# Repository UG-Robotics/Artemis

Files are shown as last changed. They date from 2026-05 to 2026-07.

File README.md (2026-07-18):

# Artemis — WRO 2026 Future Engineers

**Team Artemis · UGhana Robotics · University of Ghana**

Artemis is an autonomous self-driving vehicle built for the [WRO Future Engineers](https://wro-association.org/) 2026 season. Our core engineering idea is **one brain, two bodies**: the control logic is developed and validated in a purpose-built 2D simulator, then the *same code* drives the physical robot through a thin hardware-abstraction layer. Every algorithm on the vehicle was tuned against hundreds of simulated runs before it ever touched the mat.

## Contents

- [Repository structure](#repository-structure)
- [The challenge](#the-challenge)
- [The vehicle](#the-vehicle)
- [1. Mobility and mechanical design](#1-mobility-and-mechanical-design)
- [2. Power and sensor architecture](#2-power-and-sensor-architecture)
- [3. Software architecture](#3-software-architecture)
- [4. Engineering decisions and lessons](#4-engineering-decisions-and-lessons)
- [5. Reproducing the robot](#5-reproducing-the-robot)
- [Testing workflow](#testing-workflow)
- [Status](#status)

## Repository structure

```
artemis/
├── src/
│   ├── core/                    # Shared control brain — runs in BOTH sim and robot
│   ├── sim/
│   │   ├── open-challenge-sim/  # 2D simulator, viewer, and test suites
│   │   └── obstacle-challenge-sim/
│   └── robot/                   # Raspberry Pi runtime: drivers, HAL, entry points
│       ├── drivers/             # motor, servo, ToF, IMU, color, camera
│       ├── bench/               # per-device bring-up & diagnostic scripts
│       └── web/                 # teleop + telemetry dashboard (systemd service)
├── docs/                        # Engineering docs: power & sensors writeup, BOM, wiring PDF
├── schemes/                     # Wiring diagram (PNG/SVG) + docs/schematics/ PDF
├── models/                      # CAD: cad-source/ (STEP), print/ (STL), v1/ (retired design)
├── v-photos/                    # Vehicle photos (6 views)
├── t-photos/                    # Team photos
└── video/                       # Run videos + YouTube link (video.md)
```

## The challenge

A vehicle must complete **three autonomous laps** on a track whose geometry is randomized every round: the **Open Challenge** varies the track width between 600 and 1000 mm, and the **Obstacle Challenge** adds red/green traffic pillars (red → pass on the right, green → pass on the left), a possible mid-run direction reversal, and finishes with **parallel parking** into a slot only 1.5× the vehicle length. Official rules: [WRO Future Engineers 2026](https://wro-association.org/competition/2026-season/).

## The vehicle

Six views of the vehicle are in [`v-photos/`](v-photos). Key figures (current, generation-2 chassis — measured from the CAD assembly):

| Property | Value |
|---|---|
| Footprint over wheels | ≈ 208 mm × 148 mm (rules allow 300 × 200) |
| Height | ≈ 100 mm (equal to the track wall height; limit 300) |
| Wheelbase / track | ≈ 152 mm / ≈ 120 mm |
| Wheels | ⌀ ≈ 55 mm rubber, 4-spoke |
| Drive | Single JGA25-370 12 V DC gearmotor, rear axle |
| Steering | Front-wheel, SG90 servo, ±35° measured linkage throw |
| Compute | Raspberry Pi 3B+ |
| Power | 7.4 V 2S LiPo, 5000 mAh (built-in protection board) + XL4015 buck for the 5 V rail |

This is our **second chassis generation** (see §1 and [`models/README.md`](models/README.md) for the full story). The simulator's kinematic constants in [`src/core/config.py`](src/core/config.py) now model this chassis (208 mm, 152 mm wheelbase, ⌀55 mm wheels, 300 RPM rated drive), and the open-challenge controller was re-tuned and re-validated in simulation against the new geometry. Constants that can only be confirmed on the physical robot — such as the measured wheel RPM under load — still carry an explicit `VERIFY` marker in [`src/robot/hardware_config.py`](src/robot/hardware_config.py) until they have been bench-measured.

## 1. Mobility and mechanical design

- **Servo-driven front steering.** The front wheels steer through a king-pin linkage driven by the SG90's horn; we measured the real assembled throw at ±35° and use that as the software steering limit. Our first-generation chassis used explicit Ackermann geometry (inner wheel turns tighter — see [`models/README.md`](models/README.md)), and that design reasoning carried into the current steering setup.
- **Single-motor rear drive**, as required by the rules — one 12 V-rated DC gearmotor on the rear axle. The motor's encoder is **not used** in the current build: the controllers are deliberately encoder-free, taking distance context from the ToF array and heading from the IMU, so the wheel-RPM measurement (`VERIFY` in `hardware_config.py`) only calibrates the speed model, not a control loop.
- **Two chassis generations.** Our first fully 3D-printed design ([`models/v1/`](models/v1)) packed everything into a 140 mm shell for protection — and taught us a hard lesson: it was so cramped that every wiring fault meant a full teardown, which cost us days during electrical bring-up (§4). Generation 2 is a longer 208 mm chassis plate carrying a custom-designed **tub + lid body** ([`models/cad-source/`](models/cad-source) STEP sources, [`models/print/`](models/print) print-ready STLs): the screw-on lid comes off to expose the entire loom and every board for probing, the battery pack rides in a 24 mm service bay *under* the tub on metal standoffs, and the walls carry apertures for all four ToF sensors, the camera nose, the power switch, and the start button. The full iteration history (10 body revisions, with what each one fixed) is in [`models/README.md`](models/README.md).

## 2. Power and sensor architecture

Wiring diagram: [`schemes/circuit_image.png`](schemes/circuit_image.png) (editable SVG alongside; full schematic PDF in [`docs/schematics/`](docs/schematics)). **Full writeup — power budget, bus architecture, placement rationale, calibration procedures, and failure modes: [`docs/power-and-sensors.md`](docs/power-and-sensors.md).** Highlights:

**Power.** A 7.4 V 2S LiPo pack (5000 mAh, built-in dual-protection board, mounted in the under-tub bay) feeds the drive motor directly through the H-bridge; an XL4015 buck converter steps down to 5 V for the Pi, servo, and sensors, isolating logic from motor sag. Cost breakdown of the full build: [`docs/bom.md`](docs/bom.md).

**Sensors and why we chose them:**

| Sensor | Role | Placement rationale |
|---|---|---|
| 4× VL53L1X ToF | Wall ranging (front/left/right/rear) | Long-distance mode (≤3.6 m) covers the full 1000 mm track width with margin; left/right pair gives centring error, front detects the corner wall, rear disambiguates the start section |
| LSM6DSOX IMU | Heading (gyro-hold mode) | Bench-measured ≈0.07°/min raw drift; startup bias calibration + zero-velocity updates |
| TCS34727 color | Corner lines (orange/blue) | Downward-facing; the mat lines are the rules' ground-truth corner trigger |
| OV5647 camera | Pillar detection + heading fusion | Forward, processed on the Pi at 640×480 |

**Bus engineering that cost us real debugging time** (all documented in the code):
- All four VL53L1X ship at the same I2C address, so each is enabled sequentially via its XSHUT pin and reassigned to 0x30–0x33 at boot ([`src/robot/hardware_config.py`](src/robot/hardware_config.py)).
- The color sensor's fixed 0x29 address **clashes** with the ToF default, so it lives on its own software I2C bus (i2c-gpio overlay on GPIO20/21).
- The Pi's I2C clock is lowered to 50 kHz — at the default 100 kHz the VL53L1X's long init transactions fail intermittently on our loom.
- Every calibration constant that hasn't been verified on the physical build is explicitly marked `VERIFY` in `hardware_config.py`, so nothing silently runs on a guess.

## 3. Software architecture

Three layers ([`src/README.md`](src/README.md)):

- **`core/`** — the brain. Pure Python, no hardware imports. The primary [`Controller`](src/core/controller.py) is a state machine (below); [`WallFollowController`](src/core/wall_follow_controller.py) is a ToF-only alternative brain (§4). Both expose the identical `update(sensors, robot, track, dt)` contract.
- **`sim/`** — a 2D simulator with a pygame viewer, randomized track configs, and scored test suites.
- **`robot/`** — the Pi runtime: `RealHardware` implements the same interface the simulated robot does, so a controller cannot tell which body it is driving.

Primary controller state machine:

```mermaid
stateDiagram-v2
    [*] --> STARTING
    STARTING --> WALL_FOLLOWING
    WALL_FOLLOWING --> CORNER_TURN: corner line detected
    CORNER_TURN --> WALL_FOLLOWING: heading changed 90°
    WALL_FOLLOWING --> PILLAR_AVOIDANCE: pillar in path
    PILLAR_AVOIDANCE --> WALL_FOLLOWING: pillar cleared
    WALL_FOLLOWING --> THREE_POINT_TURN: reversal condition
    THREE_POINT_TURN --> WALL_FOLLOWING
    WALL_FOLLOWING --> PARKING: 3 laps (obstacle)
    WALL_FOLLOWING --> STOP_SECTION: 3 laps (open)
    PARKING --> [*]
    STOP_SECTION --> [*]
```

Straights are a **PD controller** on the left/right ToF difference (centring), with a heading term toward the nearest cardinal direction; corners drive a bicycle-model arc whose radius is computed live from the inner-wall distance; pillar avoidance is a bounded heading-offset "weave" that snapshots the lane heading and hinges around the pillar on the rule-mandated side. Laps are counted from the mat's colored lines with distance-based dedup (8 sections = 1 lap).

The real-robot entry point [`src/robot/open_challenge.py`](src/robot/open_challenge.py) can run **three brains** selected by flag — `--mode tof` (wall-follower, the proven baseline), `--mode fusion` (ToF + camera heading blend, 0.7/0.3), `--mode imu` (gyro heading-hold) — which lets us swap strategy at the track without code changes.

Every run is recorded by a **flight recorder** ([`src/robot/run_logger.py`](src/robot/run_logger.py)): 30 Hz sensor CSV, 10 Hz camera detections, keyframe JPEGs, and metadata including the deployed git revision. [`src/robot/bench/log_timeline.py`](src/robot/bench/log_timeline.py) replays a run as a timeline with an ASCII path plot, which is how we debug field behaviour after the fact.

## 4. Engineering decisions and lessons

The decisions that shaped the robot, with the evidence behind them:

- **Sim-first development.** Building the simulator before the robot let us tune the PD gains and corner geometry across 48 randomized edge-case configurations — all 48 complete three laps in the open-challenge suite. When hardware later failed (below), the sim is also what let us validate a replacement strategy in one evening.
- **The counterfeit IMU.** Our original "MPU6050" answered WHO_AM_I with 0x98 — a non-functional counterfeit. We replaced it with a genuine LSM6DSOX, bench-measured its drift (≈0.07°/min), and the IMU driver now **verifies the chip ID at startup** so a swapped or fake part fails loudly instead of navigating badly.
- **A second brain instead of a blocked robot.** While the IMU was dead, the gyro heading-hold controller couldn't drive. Rather than wait on parts, we wrote `WallFollowController` — open-challenge navigation from the four ToF sensors alone (no IMU, no color, no pose), validated in the sim before deployment. It remains our most robust fallback, and the `--mode` flag makes the choice a run-time decision.
- **Motor driver forensics.** The TB6612FNG's channel B died at chip level. GPIO-probe bench scripts ([`src/robot/bench/motor_test/`](src/robot/bench/motor_test)) isolated the fault to the chip rather than wiring or code; we moved the motor to channel A and left the diagnostic scripts in the repo.
- **Chassis v1 → v2** (§1): compactness lost to serviceability once real debugging started.
- **Exclusive camera ownership.** The teleop dashboard and the autonomous runtime both want the camera; Picamera2 allows one owner. The run entry point guards against the web service holding it, and the boot-run systemd unit declares `Conflicts=artemis-web` so the two can never fight during a competition start.

## 5. Reproducing the robot

**Build:** print everything in [`models/print/`](models/print) (PLA, 0.2 mm layers; STEP sources in `cad-source/` for modification), assemble per the mechanical notes in [`models/README.md`](models/README.md), and wire following [`schemes/`](schemes).

**Pi setup (Raspberry Pi OS):**
1. In `/boot/firmware/config.txt`: enable I2C with `dtparam=i2c_arm_baudrate=50000`, and add the software I2C bus for the color sensor: `dtoverlay=i2c-gpio,bus=3,i2c_gpio_sda=20,i2c_gpio_scl=21`.
2. Install dependencies: `pip install -r requirements-robot.txt` plus the apt packages listed in that file (`picamera2`/`opencv` install via apt on Raspberry Pi OS).
3. Copy the repo's `src/` to `/home/pi/artemis/src` (we deploy with `rsync`; the deploy stamps the git revision into `DEPLOYED_REV` so run logs record which code ran).
4. Verify each device independently with the scripts in [`src/robot/bench/`](src/robot/bench) (I2C scan, per-sensor live reads, servo jog, motor probe, button test), then fill in any `VERIFY` constants in `hardware_config.py`.

**Run:**
```bash
# On the Pi, from /home/pi/artemis/src:
python3 -m robot.open_challenge                    # ToF-only, waits for start button
python3 -m robot.open_challenge --mode imu --direction cw
python3 -m robot.web.app                           # teleop/telemetry dashboard :8000
```
For competition starts with no laptop attached, the `artemis-run` systemd unit boots the Pi straight to button-armed in ≈23 s, runs exactly one attempt, and cuts motors on stop ([`src/robot/artemis-run.service`](src/robot/artemis-run.service)).

**Simulator (any machine):**
```bash
pip install -r requirements.txt
cd src/sim/open-challenge-sim
python sim_viewer.py        # real-time visualizer (SPACE pause, ←/→ configs, T sensor rays)
python test_pd_tuning.py    # scored PD/navigation suite
```

## Testing workflow

Full documentation with the per-suite pass bars: [`tests.md`](tests.md). In short:

1. **Simulate** — every control change must pass the scored sim suites (`test_pd_tuning.py`, `test_open_score.py`, plus headless and sensor-noise tests) across the randomized configs before it is deployed.
2. **Bench** — new or repositioned hardware goes through its `robot/bench/` script in isolation before joining the control loop.
3. **Field + flight recorder** — real runs are logged automatically (sensors, camera, frames, git revision) and replayed with `log_timeline.py`; changes prompted by a field failure are reproduced in the sim first, fixed in `core/`, and re-validated so sim and robot never diverge.

## Status

- **Open challenge:** ToF wall-follower validated in sim (48/48 edge-case configs, 30/30 score) and driving on the physical robot; on-mat tuning in progress.
- **Obstacle challenge:** pillar-avoidance and parking logic complete in the primary controller and sim; camera color calibration and on-robot integration in progress.
- Run videos: [`video/video.md`](video/video.md).

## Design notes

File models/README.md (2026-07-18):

# Models — mechanical design & CAD

CAD for the Artemis vehicle, in two generations:

```
models/
├── cad-source/   # Current (gen-2) design — editable STEP sources
│   ├── New assembly test on new.step   # Full rolling-chassis assembly (frame,
│   │                                   #  wheels, steering, JGA25-370, SG90, tub)
│   ├── New assembly test on new.f3d    # Fusion 360 source of the assembly
│   ├── full_assembly_with_lid.step     # Assembly + lid placed (render-ready)
│   ├── Improved frame.step   # Chassis base plate (71 × 171 mm)
│   ├── body.step             # Tub + lid combined, in assembled position
│   ├── body_tub.step / body_lid.step / legs.step
│   └── *_print.stl           # Bed-oriented exports (duplicated in print/)
├── print/        # Current design — print-ready STLs
└── v1/           # Retired first-generation design (kept for the record)
```

## Current design (generation 2, July 2026)

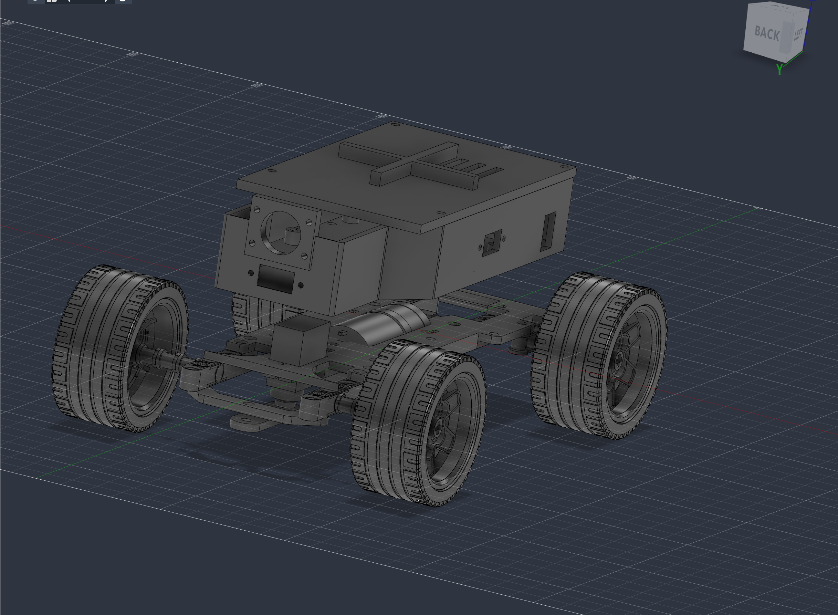
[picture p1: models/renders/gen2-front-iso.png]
Gen-2 assembly, front isometric render

<div align="center">
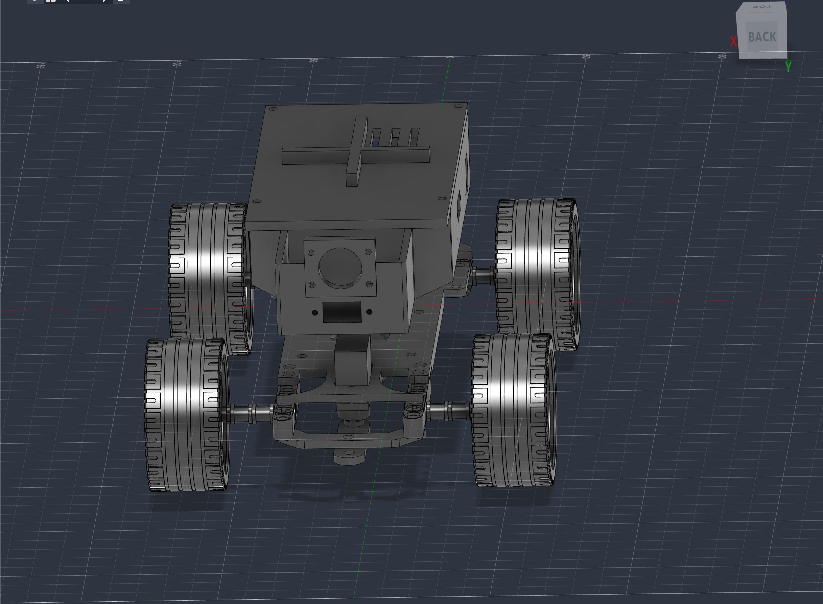
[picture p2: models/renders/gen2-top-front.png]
Gen-2 top-front render

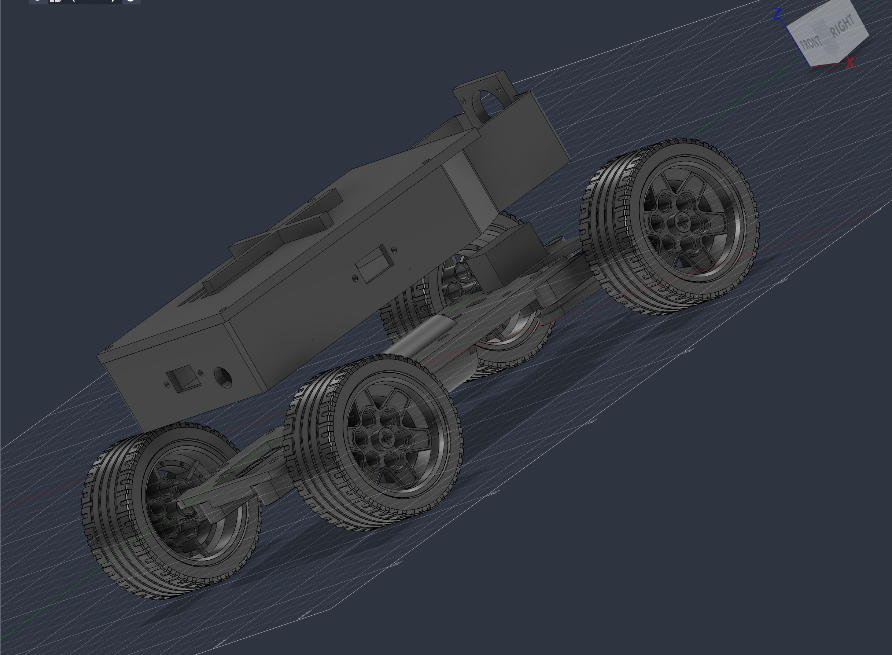
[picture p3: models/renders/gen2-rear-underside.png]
Gen-2 rear underside render

</div>

*Renders of [`cad-source/full_assembly_with_lid.step`](cad-source/full_assembly_with_lid.step) in Fusion 360 — lid on, camera nose and ToF/button apertures visible.*

The vehicle is built on a **208 mm chassis** (measured over the wheels: ≈208 L × 148 W mm, ≈100 mm tall — exactly the track wall height, well inside the 300 × 200 × 300 limit). The rolling chassis — frame plate, steering, motor, and ⌀≈55 mm wheels, wheelbase ≈152 mm — was built by our mechanical engineer; the **body is our own design**.

### Body architecture: tub + lid

- **Tub** (`body_tub`): an open box that screws onto the frame's top-deck M3 holes and hosts the Raspberry Pi 3B+ on a standard 58 × 49 mm standoff pattern. The walls carry purpose-cut apertures: horizontal 14 × 8 mm windows for all four VL53L1X ToF boards (front/left/right/rear, boards self-tapped to the wall), a camera nose tower for the OV5647, the power rocker on the left wall, and the 12 mm start button on the rear wall. Seven floor pass-throughs route the loom.
- **Lid** (`body_lid`): a 3.5 mm screw-on cover (6 screws). The IMU bolts up through the lid into its stiffening ribs — an earlier revision used a printed boss, which we deleted when rib-mounting proved stiffer against motor vibration. The nose is deliberately left open so the lid never occludes the camera.
- **Under-tub service bay**: the tub floor sits 24 mm above the frame on **4 × M3×24 metal hex standoffs**, creating a bay beneath it for the heaviest item — the battery — kept low and central for stability. The bay was originally sized around a 3 × 18650 holder (75 × 60 × 18 mm); the pack has since been replaced by a 2S LiPo brick that lives in the same bay. `legs.step` is an optional printed alternative to the standoffs.

**Serviceability is the design's organizing principle** (see *Why we redesigned* below): lid off = every board and the full loom exposed; battery slides out of the open-sided bay without touching the electronics.

### Print notes

Printed on a Bambu Lab P1S, PLA, 0.2 mm layers. `body_tub_print.stl` and `body_lid_print.stl` are already bed-oriented: the tub prints floor-down (light supports only in window/aperture overhangs), the lid prints flat with **no supports**. All holes are self-tap pilot or clearance sizes — no printed threads.

### Iteration history (what ten body revisions taught us)

The body went through ~10 design revisions before printing. The instructive failures:

1. **The battery drove the architecture.** The 60 mm-wide holder physically could not fit between the tub's original corner legs on a 71 mm frame plate. We evaluated three placements (under-chassis, in-tub, on-lid) against center-of-mass and access, and settled on the under-tub bay — the decision that produced the standoff design.
2. **Integral legs doubled the print.** Printing the tub with its four 24 mm legs forced ~35 g of tree support under the raised floor and pushed the print past 5 hours. Deleting the legs (tub flat on the bed) and bridging with metal standoffs cut support material to grams — and the metal is stronger anyway.
3. **Wall cut-outs must overshoot.** Twice, a window boolean that extended exactly *to* the inner wall face left a 0.5 mm skin over the opening. Rule adopted: every cut box extends past the face it opens.
4. **Fit is checked against measured boards, not datasheet folklore.** The first external body design had the Pi hole pattern, switch cut-out, and ToF mounts wrong; we re-measured every component before modeling. The ToF windows also flipped from vertical to horizontal once we checked the actual board's long axis.
5. **Controls placement followed usage.** The start button began on the left wall 1.5 mm from the Pi — reachable, but only just. It ended up on the rear wall next to the rear ToF, 20+ mm clear of everything, where a start press can't disturb the wiring.

## Generation 1 (retired — `v1/`)

The first vehicle was a fully 3D-printed 140 × 88 × 56 mm design (76 mm wheelbase, ⌀30.4 mm LEGO wheels) built around two objectives: **compactness and component protection**. Everything lived inside the shell to protect the electronics, with a slip-fit body-to-chassis joint and ventilation cut-outs.

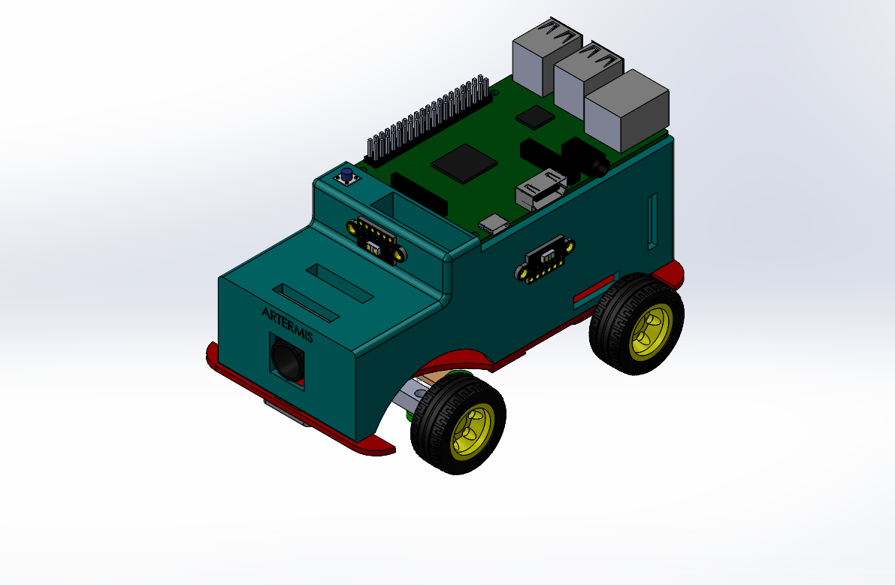
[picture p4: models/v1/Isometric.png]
v1 isometric view


Its mechanical highlights, which still inform the current vehicle:

- **Ackermann steering geometry** — the inner wheel turns at a greater angle than the outer during cornering, reducing slip; actuated by the servo horn directly on the steering linkage. We validated the geometry in simulation before printing:

  v1 steering simulation

- **Single-motor rear drive through a custom gearbox** (bevel gears, 1:1 ratio) — the ratio preserved the motor's rated speed, prioritizing lap time over torque, because the vehicle was light enough that torque was never the constraint. A wheel encoder was wired for odometry experiments, but never adopted — the control stack ended up deliberately encoder-free (ToF distances + gyro heading).
- **Iterative chassis lightening** — material removed for steering clearance, thinner base with reinforcement extrusions at load points:

  <div align="center">
  v1 first chassis iteration ➡️
  v1 final chassis iteration
  </div>

**Why we retired it:** the very compactness we optimized for became the bottleneck the moment electrical bring-up started. Diagnosing a single suspect jumper meant disassembling the stacked body, and with the debugging phase producing faults weekly (dead motor-driver channel, counterfeit IMU, sensor repositioning — see the [root README §4](../README.md#4-engineering-decisions-and-lessons)), teardown cost dominated. The 208 mm generation-2 platform trades footprint for a longer wheelbase (steadier tracking), larger wheels, and above all **access**: nothing on the current robot requires removing more than the lid to reach.

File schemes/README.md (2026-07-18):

# Schemes — wiring & electromechanical diagrams

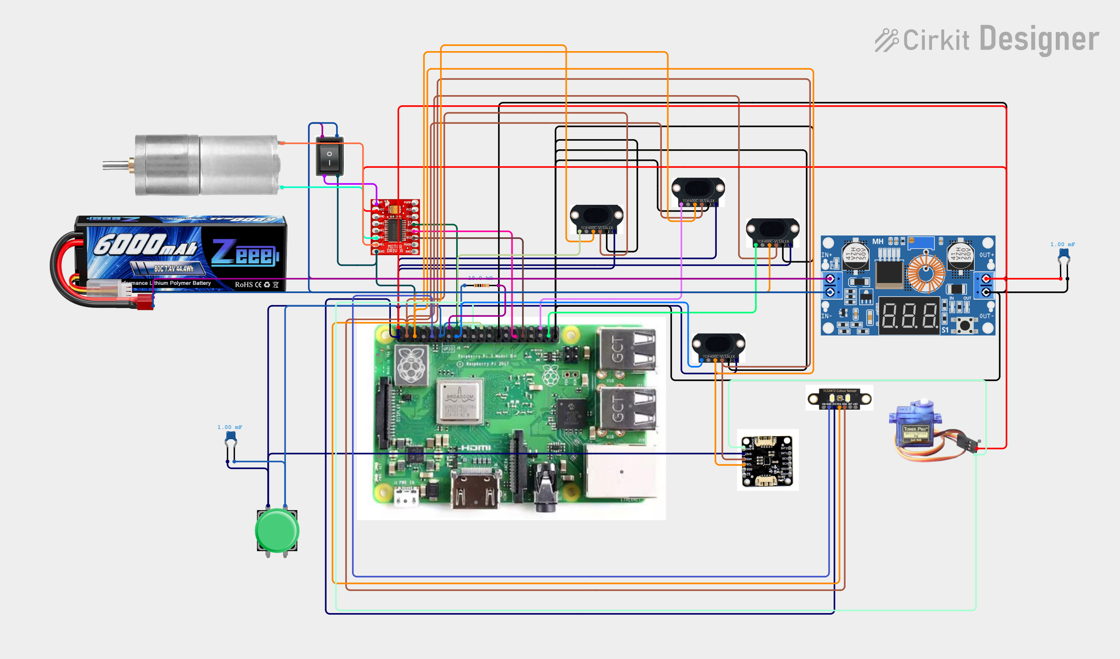
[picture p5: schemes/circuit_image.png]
Artemis Wiring Diagram


Full schematic PDF: [`../docs/schematics/`](../docs/schematics) · previous revision (2026-07-03): [`archive/`](archive)

The diagram (updated 2026-07-18 in Cirkit Designer) shows the complete electrical system: the **7.4 V 2S LiPo pack** feeding the TB6612FNG motor driver directly and the XL4015 buck producing the 5 V rail for the Raspberry Pi 3B+, SG90 steering servo, and sensor set — 4× VL53L1X ToF via individual XSHUT lines, LSM6DSOX IMU, TCS34727 color sensor, plus the DC gearmotor, start button (with 10 kΩ pulldown), and power switch. The OV5647 camera connects via the Pi's CSI ribbon and is not part of the GPIO loom.

Notes (pin-level ground truth is always [`../src/robot/hardware_config.py`](../src/robot/hardware_config.py)):
- The battery is drawn with a generic 2S LiPo illustration; the actual pack is a **7.4 V 5000 mAh (37 Wh) "Xtreme 1"** with a built-in dual-protection board — label photo: [`../docs/images/battery-2s-lipo-label.jpeg`](../docs/images/battery-2s-lipo-label.jpeg).
- The servo signal line physically passes through a level-shifter channel (LV1→HV1) that the diagram omits.
- The motor drives from TB6612 **channel A** (channel B failed at chip level — root README §4), and its encoder is **unused**: the control stack is encoder-free.
- The color sensor sits on a dedicated software I2C bus (GPIO20/21) to escape the address clash with the ToF boot sequence.

The 2026-07-03 revision in [`archive/`](archive) documents the earlier build state (MPU6050 before the counterfeit swap, 3×18650 pack, level shifter in the motor path) — kept as part of the iteration record.

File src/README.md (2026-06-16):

# Control Software

Control software for Team Artemis's WRO 2026 Future Engineers vehicle.

The control logic is shared between simulation and the real robot: a single
`core` package holds the "brain" (state machine, PD control, tuned constants),
and both the simulator and the physical robot supply their own sensors and
actuators behind the same interface.

## Structure

```
src/
├── core/                       # Shared, hardware-independent control brain
│   ├── config.py               # Physics, control, sensor and scoring constants
│   ├── controller.py           # State machine and control logic
│   └── sensors.py              # SensorReading — the perception→control contract
├── sim/
│   ├── open-challenge-sim/     # Open challenge simulation & test suite
│   └── obstacle-challenge-sim/ # Obstacle challenge simulation (planned)
└── robot/                      # Physical robot control (Raspberry Pi) — scaffold
```

`core` is imported by both `sim` and `robot`, so tuning validated in simulation
carries directly to the real vehicle.

## Open challenge simulation

A 2D Pygame model of the track, robot, and sensors used to develop and validate
the controller. See [sim/open-challenge-sim/README.md](sim/open-challenge-sim/README.md).

```bash
cd sim/open-challenge-sim
python sim_viewer.py        # real-time visualizer
python test_pd_tuning.py    # PD/navigation test suite
python test_headless.py     # headless integration test
```

The entry-point scripts add `src/` to the path so `import core...` resolves when
run directly from their folder.

## Robot

Physical-vehicle code that reuses `core` and adds hardware drivers behind a
hardware-abstraction layer. Currently a scaffold — see
[robot/README.md](robot/README.md) for the layout and the remaining porting work.

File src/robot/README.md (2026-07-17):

# Robot — physical vehicle control (Raspberry Pi)

Control code that runs on the real Artemis vehicle. It reuses the shared control
brain in [`../core/`](../core/) (the `Controller` and tuned `config`) and adds the
hardware drivers behind a single abstraction layer, so the same logic validated
in simulation drives the real robot.

> **Status: driving.** The drivers are implemented and bench-verified, and the
> open challenge runs on the vehicle via `robot.open_challenge` (ToF-only
> `WallFollowController` by default; `--mode fusion` / `--mode imu` selectable).
> The *Porting gap* below applies to the primary gyro `Controller`'s remaining
> sim-only assumptions, not to the ToF-only path.

## Layout

| File | Purpose |
|---|---|
| `hal.py` | The `Hardware` contract the controller needs, plus `RealHardware` that composes the drivers and assembles a `SensorReading`. |
| `main.py` | Control-loop entry point; documents the porting gap. |
| `hardware_config.py` | Pins, I2C addresses, and calibration constants — every uncertain value is marked `VERIFY`. |
| `drivers/` | One module per device: `motor`, `servo`, `tof`, `imu`, `color`, `camera`. |

Physics and control constants stay in `core/config.py` (shared with the sim).
Only build-specific wiring/calibration lives in `hardware_config.py`.

## How it fits together

```
core.Controller.update(sensors, robot, track, dt)
        ▲              ▲        ▲      ▲
        │   SensorReading      │   OpenChallengeWorld (main.py)
        │   from RealHardware  │
        │                  RobotIO (main.py) → RealHardware actuators
        └── same call the simulation makes
```

`RealHardware` satisfies the same interface the sim's `Robot` does, so the
controller is unchanged between the two.

## Porting gap (what's left before it runs)

The controller assumes two sim-only things; both are stubbed in `main.py`:

1. **Pose** — it reads `robot.x/y/angle`. For the open challenge this is really
   just the line-dedup in `_detect_lines`, which a dead-reckoned distance
   estimate covers (heading's already from the IMU; the build is encoder-free).
2. **Track map** — there isn't one. `OpenChallengeWorld` fakes the few values it
   asks for; returning `None` for the section query falls back to sensor/heading
   logic.

The obstacle challenge needs more (camera pillar geometry) — later.

## Bring-up order (suggested)

1. Check the wiring against `schemes/` and fill in the `VERIFY` values in
   `hardware_config.py` — measure the motor's real output RPM early, since the
   speed model depends on it.
2. Implement and bench-test each driver in `drivers/` independently.
3. Implement the `PoseEstimator` / track model (porting gap) for the open
   challenge.
4. Tune on the real track; feed any control changes back into `core/` so the
   simulation stays in sync.

## Dependencies (Pi)

Driver imports are guarded, so this package imports on a dev machine without
these. On the Pi you will need (confirm exact packages during bring-up):
`RPi.GPIO` (or `pigpio`), `smbus2`, the Adafruit CircuitPython ToF/color
libraries, and `picamera2` + `opencv` for the obstacle-challenge camera.

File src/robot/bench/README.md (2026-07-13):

# Bench — hardware bring-up & debugging tools

Standalone throwaway tools for testing one component at a time during robot
bring-up. These are **not** part of the control loop — they run directly on the
Pi (or on an Arduino Uno used as a probe) to isolate wiring/driver problems
before wiring a device into `drivers/`.

| Tool | Runs on | What it does |
|---|---|---|
| `i2c_scan/i2c_scan.ino` | Uno | Scan the I2C bus; TCS34725 colour sensor should show at `0x29`. |
| `color_test/color_test.ino` | Uno | Read raw RGB/clear from the TCS34725. |
| `tof_test/live_read.py` | Pi | Bring up all four VL53 ToFs via XSHUT re-addressing (`0x30`–`0x33`) and stream distances. |
| `servo_test/jog.py`, `jog_pi.py` | dev / Pi | Interactive steering-servo jogger (µs pulse) for finding centre and throw limits. `jog_pi.py` uses pigpio on the Pi. |
| `servo_test/servo_test.ino` | Uno | Sweep the servo from an Uno. |
| `motor_test/tb6612_uno_test*`, `chA_spin_test` | Uno | Drive the TB6612 motor driver directly to isolate the dead channel B. |
| `motor_test/uno_passive_probe` | Uno | Passive voltmeter: Pi drives the TB6612, Uno reads A01/A02 outputs. |
| `power_watch/power_watch.sh` (+ `.service`) | Pi | Log Pi power health (`vcgencmd get_throttled`) at boot then every 10 s. |

See each file's header comment for exact wiring and run instructions. Findings
from these tools are recorded in the bring-up notes (`docs/`, memory).

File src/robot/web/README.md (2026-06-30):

# Web control panel

Manual teleop served by the Pi: a camera livestream with steering (◀ ▶, left) and
throttle (▲ ▼, right) pads, a speed slider, and an E‑STOP. Touch or keyboard
(WASD / arrows). **Dev/test tool only** — the WRO competition run is fully
autonomous and wireless-free; don't run this during a scored round.

## Run

```sh
cd src
python -m robot.web.app          # or: PYTHONPATH=src python -m robot.web.app
```

Open `http://<pi-ip>:8000`. On a dev machine (no robot) it starts in **SIMULATED**
mode: the camera shows a placeholder and the pads just log intent. On the Pi it
drives the real motor/servo once those drivers are implemented.

## Dependencies

- Server: Python stdlib only.
- Camera: `picamera2` on the Pi (real stream), or `Pillow` for the dev placeholder.

## Start on boot

```sh
sudo cp src/robot/web/artemis-web.service /etc/systemd/system/
# edit User= / WorkingDirectory= to match your install path
sudo systemctl enable --now artemis-web
```

## Safety

- **Deadman watchdog:** the robot stops if no control message arrives within
  ~0.6 s (tab hidden, page closed, Wi‑Fi drop). The browser also stops on blur /
  tab-hide and sends a heartbeat while a pad is held.
- Throttle is scaled by the speed slider (default 40%).
- Actuator calls are wrapped; if a driver isn't wired up the panel reports
  SIMULATED instead of crashing.

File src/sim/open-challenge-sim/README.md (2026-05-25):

# Control Software — Simulation and Testing

This directory contains the autonomous driving control system simulation for the WRO 2026 Future Engineers Open Challenge.

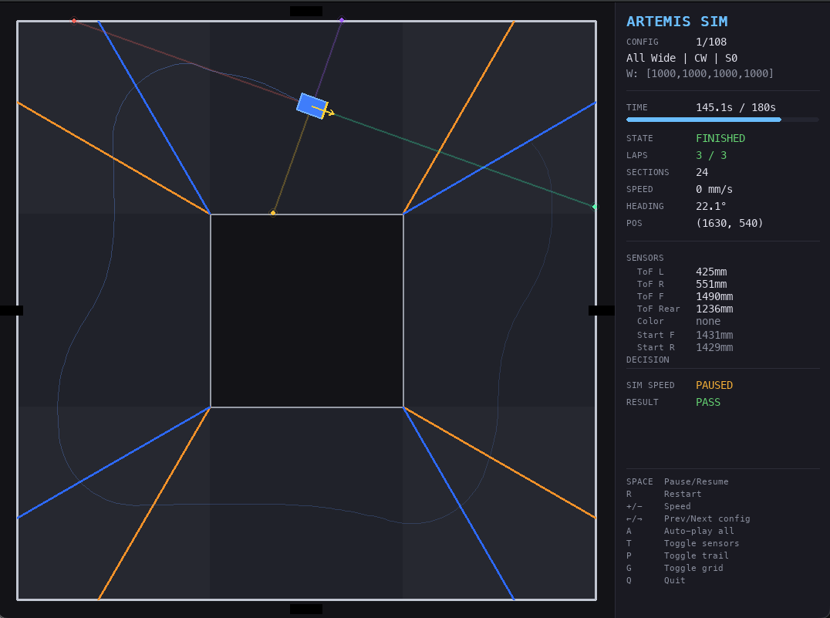
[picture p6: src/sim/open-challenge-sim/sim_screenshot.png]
Artemis Simulation — 3 laps completed


## Files

### Core Simulation Modules

**config.py**
- Global configuration constants
- PD control gains (KP_WALL, KD_WALL)
- Speed parameters (SPEED_CRUISE, MAX_SPEED)
- Track dimensions and sensor specifications
- Control frequency (CONTROL_HZ = 50 Hz)

**robot.py**
- 2D kinematic robot model
- Sensor simulation:
  - ToF (time-of-flight) distance sensors
  - IMU (accelerometer + gyroscope) heading
  - Color line detection
- Motor command processing (speed, steering)

**track.py**
- Track layout representation
- Straight sections and corner sections
- Wall collision detection
- Color line zones (orange/blue for section detection)
- Track width variation (supports 600mm and 1000mm widths)

**controller.py**
- State machine controller
- PD wall-following algorithm
- Corner turn detection and navigation
- Pillar avoidance logic
- Three-point turn maneuver
- Parking maneuver (obstacle challenge)
- Section/lap counting

### Testing & Visualization

**test_pd_tuning.py**
- Comprehensive test suite with 5 phases:
  1. Straight-line stability (centered placement)
  2. Corner exit recovery
  3. Off-center lateral offset + heading error
  4. Combined offset + angle (real-world tolerance)
  5. Corner entry with non-cardinal heading

- 108 total test configurations covering:
  - 6 track width patterns
  - 2 driving directions (CW/CCW)
  - 4 starting sections
  - ±75/100mm lateral offsets
  - ±5/12° heading errors
  
- Scores tests as PASS/FAIL with points allocation
- Generates detailed failure analysis

**sim_viewer.py**
- Real-time Pygame-based 2D visualizer
- Live simulation rendering at 60 FPS
- Features:
  - Track with walls and color lines
  - Robot with heading indicator
  - Sensor ray visualization
  - Path trail rendering
  - Real-time telemetry panel showing:
    - Position (x, y)
    - Heading (IMU)
    - Speed
    - State machine status
    - Lap/section counting
    - Sensor readings (ToF L/R/F, color detected)
    - Current decision/action
  - Config list for quick navigation (108 test cases)
  - Auto-play mode for batch testing
  - Adjustable simulation speed (1x to 16x)

## Quick Start

### Run Single Test Configuration
```bash
python sim_viewer.py
```
- View real-time simulation with telemetry
- Use L to open config list and jump to any test
- Use A to auto-play all 108 configurations

### Run Full Test Suite
```bash
python test_pd_tuning.py
```
- Executes all 108 test cases headlessly
- Reports pass/fail rate and points per phase
- Shows failure statistics and patterns

## Algorithm Summary

### PD Wall-Following

The core control algorithm uses proportional-derivative (PD) feedback:

```
error = tof_right - tof_left
steering = KP_WALL * error + KD_WALL * (error - prev_error)
```

With adaptive gains based on track width:
- Narrow tracks (≤700mm): Higher gains for stability
- Wide tracks (>900mm): Lower gains to prevent oscillation

### State Machine

1. **STARTING** → Initialize, store starting ToF readings, begin driving
2. **WALL_FOLLOWING** → PD centering and line detection
3. **CORNER_TURN** → Navigate corners with heading correction
4. **PILLAR_AVOIDANCE** → Detect and avoid obstacles
5. **THREE_POINT_TURN** → Execute reversal maneuver
6. **PARKING_APPROACH** → Approach parking zone
7. **PARKING_EXECUTE** → Execute parking maneuver (obstacle)
8. **STOP_SECTION** → Verify starting section via ToF fingerprint
9. **FINISHED** → Complete and stop (open challenge)
10. **STOPPED** → Time limit reached

## Testing Framework

### Configuration Space

Test configurations vary along multiple dimensions:

```
Config = (track_widths, direction, start_section, offset, angle_offset)

track_widths: 6 patterns (all-wide, all-narrow, alternating, etc.)
direction:   CW (1) or CCW (-1)
start_section: 0-3 (each of 4 straight sections)
offset:      -100mm to +100mm (lateral displacement)
angle_offset: -12° to +12° (heading error)
```

### Scoring

- **3 points** — Converged (lateral error < threshold, heading < 5°)
- **2 points** — No collision (partial success)
- **0 points** — Wall collision or timeout

## Dependencies

- Python 3.8+
- pygame 2.0+ (for sim_viewer.py)

---

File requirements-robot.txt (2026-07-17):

# Raspberry Pi runtime (Raspberry Pi OS). Install on the Pi, not the dev machine.
# System packages (apt): python3-picamera2 python3-opencv python3-pigpio
RPi.GPIO
pigpio
smbus2
pyserial
adafruit-blinka              # board/busio CircuitPython compat layer
adafruit-circuitpython-vl53l1x
adafruit-circuitpython-busdevice
numpy

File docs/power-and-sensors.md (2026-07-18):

# Power & Sensor Architecture

Companion to the wiring diagram in [`../schemes/`](../schemes) (full schematic PDF in [`schematics/`](schematics)). This doc covers how power is distributed and budgeted, why each sensor is where it is, how everything is calibrated, and the failure modes we guard against.

## 1. Power architecture

```
2S LiPo pack (7.4 V nominal, 5000 mAh / 37 Wh, built-in dual-protection board)
 ├── TB6612FNG VM ──► drive motor (12 V-rated JGA25-370 gearmotor)
 └── XL4015 buck ──► 5 V rail
        ├── Raspberry Pi 3B+ (+ OV5647 camera via CSI)
        ├── SG90 steering servo
        └── sensor set (4× VL53L1X, LSM6DSOX, TCS34727) via the Pi's 3V3/5V pins
```

> **Battery history:** the build originally used a 3×18650 holder (11.1 V 3S). It was replaced with a single 7.4 V 2S LiPo brick ([label photo](images/battery-2s-lipo-label.jpeg): Xtreme 1, 5000 mAh / 37 Wh, 8.4 V max charge) — higher capacity, a built-in dual-protection circuit board, and a single rigid unit in the under-tub bay instead of a holder with spring contacts (a vibration liability). The 12 V-rated motor now runs below rated voltage, which is fine for us — the sim retune showed the vehicle is driven at ~35% throttle anyway — and the actual wheel RPM at pack voltage is exactly what the `OUTPUT_RPM` `VERIFY` measurement will pin down.

Two deliberate separations:

- **Motor current never crosses the logic rail.** The motor draws directly from the pack through the H-bridge; the buck isolates the 5 V rail from motor sag and inrush, so a stall can't brown out the Pi mid-run.
- **The buck output is set with a multimeter, capped at 5.2 V.** The Pi can detect under-voltage but not over-voltage, so the upper bound is enforced at calibration time, not in software (documented in [`../src/robot/bench/power_watch/power_watch.sh`](../src/robot/bench/power_watch/power_watch.sh)).

### Power budget (datasheet-typical; on-robot measurement is on the bench list)

| Load | Rail | Typical | Peak | Notes |
|---|---|---|---|---|
| Raspberry Pi 3B+ | 5 V | ~350–700 mA | ~1.2 A | Higher end with camera streaming + 4-sensor polling |
| OV5647 camera | 5 V (via Pi) | ~250 mA | — | Counted inside the Pi's loaded figure |
| SG90 servo | 5 V | ~10 mA idle, 100–250 mA moving | ~650 mA stall | Peak only at mechanical limit |
| 4× VL53L1X | 3V3 | ~80 mA (4 × ~20 mA ranging) | ~110 mA | Continuous long-distance ranging |
| LSM6DSOX | 3V3 | <1 mA | — | |
| TCS34727 | 3V3 | <1 mA | — | Own software I2C bus (see §2) |
| TB6612 logic | 3V3 | ~2 mA | — | |
| **5 V rail total** | | **~0.5–1.1 A** | **~2 A** | XL4015 is rated 5 A — >2× headroom at worst case |
| Drive motor | pack | load-dependent | ≤ TB6612 limit | TB6612 channel: 1.2 A continuous / 3.2 A peak; the JGA25-370 is driven at ~35% throttle in normal running, and a sustained stall is a fault state the controller never commands |

### Runtime power monitoring

A watchdog service ([`power_watch.sh`](../src/robot/bench/power_watch/power_watch.sh)) polls the Pi's `vcgencmd get_throttled` flags every 10 s and logs any under-voltage, frequency-capping, or thermal-throttle event — including the sticky "has occurred since boot" bits, so a transient brown-out during a run is caught even if we look hours later. This is how we verify the power budget in practice rather than trusting the arithmetic above.

## 2. Bus architecture (lessons included)

All I2C devices share the Pi's hardware bus **except** the color sensor. Three non-obvious choices, each bought with debugging time:

1. **ToF address assignment at boot.** All four VL53L1X ship at address 0x29. Each sensor's XSHUT line goes to its own GPIO; at startup we hold all four in reset, then enable them one at a time and reassign to 0x30–0x33 ([`../src/robot/hardware_config.py`](../src/robot/hardware_config.py)).
2. **The color sensor gets its own bus.** The TCS34727's address is fixed at 0x29 — the exact address the ToFs default to during their staggered boot. Rather than fight the race, the color sensor lives on a dedicated software I2C bus (`i2c-gpio` overlay, SDA=GPIO20 / SCL=GPIO21 → `/dev/i2c-3`).
3. **The hardware bus runs at 50 kHz, not the default 100 kHz.** The VL53L1X's long init sequences failed intermittently on our loom at 100 kHz; halving the clock (`dtparam=i2c_arm_baudrate=50000`) made init deterministic. Slower bus, but with a 50 ms ranging budget per sensor the bus is nowhere near the bottleneck.

## 3. Sensor selection & placement

| Sensor | Why this part | Why this position |
|---|---|---|
| 4× VL53L1X ToF (front/left/right/rear) | Long-distance mode ranges to 3.6 m — full 1000 mm track width plus diagonal views, where a VL53L0X (1.36 m) would clip | Body windows put the beams **below the 100 mm wall top**, so a ray always terminates on wall, not open air. Left/right opposing pair → centring error `right − left` in one subtraction; front → corner-wall detection and turn radius; rear → start-section signature for the finish stop |
| LSM6DSOX IMU | Replaced a counterfeit "MPU6050" (see §4). Bench-measured ≈0.07°/min raw gyro drift — ~0.2° over a 3-minute run before fusion | Inside the tub, screwed to the lid's stiffening ribs: rigid mount, away from the motor, because gyro noise is dominated by mechanical vibration coupling |
| TCS34727 color | Detects the mat's orange/blue corner lines — the rules' ground-truth lap/corner reference | Facing straight down through a floor aperture at controlled ride height; ambient-light-proof compared to aiming a camera at the mat |
| OV5647 camera (160° wide-angle) | Pillar color+bearing for the obstacle challenge; heading fusion for the open challenge | High on the body nose: wide FOV covers both track sides; mounted inverted for cable routing, corrected in-sensor (180° flip) so every consumer sees an upright frame |

**ToF timing budget:** 50 ms per sensor → the 4-sensor array refreshes at ~20 Hz, matched to the control loop rate. Long-distance mode + 50 ms is the datasheet-recommended pairing for full range.

**ToF de-noising** ([`../src/core/tof_filter.py`](../src/core/tof_filter.py)): the VL53L1X occasionally drops a single frame to a spurious value (usually the 4 m no-target sentinel). We run a two-stage per-channel filter — an outlier gate that rejects physically-impossible frame-to-frame jumps unless two consecutive samples agree (a genuine wall edge passing), then a rolling median. A median was chosen over a low-pass deliberately: it never smears a spike into neighbouring samples and adds at most one frame of lag. The *same filter code* runs in the simulator (fed with bench-measured dropout rates), which is how the escape-valve tuning was validated: an early gate version held stale readings through full-lock turns and dropped the narrow-track sim suite from 10/10 to 0/10 — the sim caught it before the track did.

## 4. Calibration procedures

**IMU (every power-on, automatic):**
1. Chip-ID check first — the driver reads WHO_AM_I and refuses to start on a mismatch. This exists because our original "MPU6050" was a counterfeit that answered 0x98 and produced garbage; a fake or mis-wired part now fails loudly at boot instead of navigating badly.
2. Stationary bias calibration: 600 gyro samples averaged while the robot is still (the boot-to-button service does this during startup, which is why the robot must not be moved right after power-on).
3. Zero-velocity updates (ZUPT) during the run: whenever gyro and accelerometer both read "not moving", the heading is frozen and the bias estimate refined — bounding drift between corners.
4. Mounting sign verified empirically: a commanded 90° right turn swept −90.9° raw, so the Z-axis sign is inverted in config (`GYRO_Z_SIGN = -1`) — measured, not assumed.

**ToF array:** after any physical repositioning, each sensor is verified with a hand-wave test against its label. This rule exists because we once repositioned the sensors and three of the four labels ended up on the wrong axes — the array "worked" electrically while reporting geometry that was simply wrong.

**Servo:** the linkage is jogged over its range with [`bench/servo_test`](../src/robot/bench/servo_test) to record the real center/min/max pulse widths and the measured ±35° mechanical throw; software commands are clamped to that measured limit, and a slew-rate limit (90°/s) keeps steering transients from shocking the linkage.

**Color & camera (venue-dependent, calibrated at the competition table):** the TCS34727 orange/blue thresholds and the camera's red/green HSV ranges are lighting-dependent, so they are treated as *deployment* calibration, not constants — both are explicitly `VERIFY`-marked in `hardware_config.py` and re-measured on the actual mat.

**Discipline for everything above:** any physical constant that has not been measured on this build is marked `VERIFY` in [`hardware_config.py`](../src/robot/hardware_config.py). The marker is grep-able, so "what still runs on a guess" is a one-line query, not tribal knowledge.

## 5. Failure modes considered

| Risk | Mitigation |
|---|---|
| Motor stall browns out the Pi | Separate motor path from the 5 V rail via the buck; `power_watch` logs any under-voltage flag it misses |
| Counterfeit / mis-wired I2C part | WHO_AM_I verification at boot (policy adopted after the fake-IMU incident) |
| I2C address collision (ToF vs color) | Dedicated software bus for the color sensor; staggered XSHUT boot for the ToFs |
| Single-frame ToF glitches steering | Outlier gate + median filter, identical in sim and robot |
| Gyro drift over a 3-minute run | Warm-up-aware bias cal + ZUPT + drift bench-measured before trusting the sensor; ToF-only controller as a full fallback brain |
| Camera contention (dashboard vs run) | Picamera2 single-owner guard + `Conflicts=artemis-web` in the run service |
| Dead driver channel (it happened) | Bench probe scripts in [`bench/motor_test`](../src/robot/bench/motor_test) isolate chip vs wiring vs code in minutes; motor moved to the healthy channel |

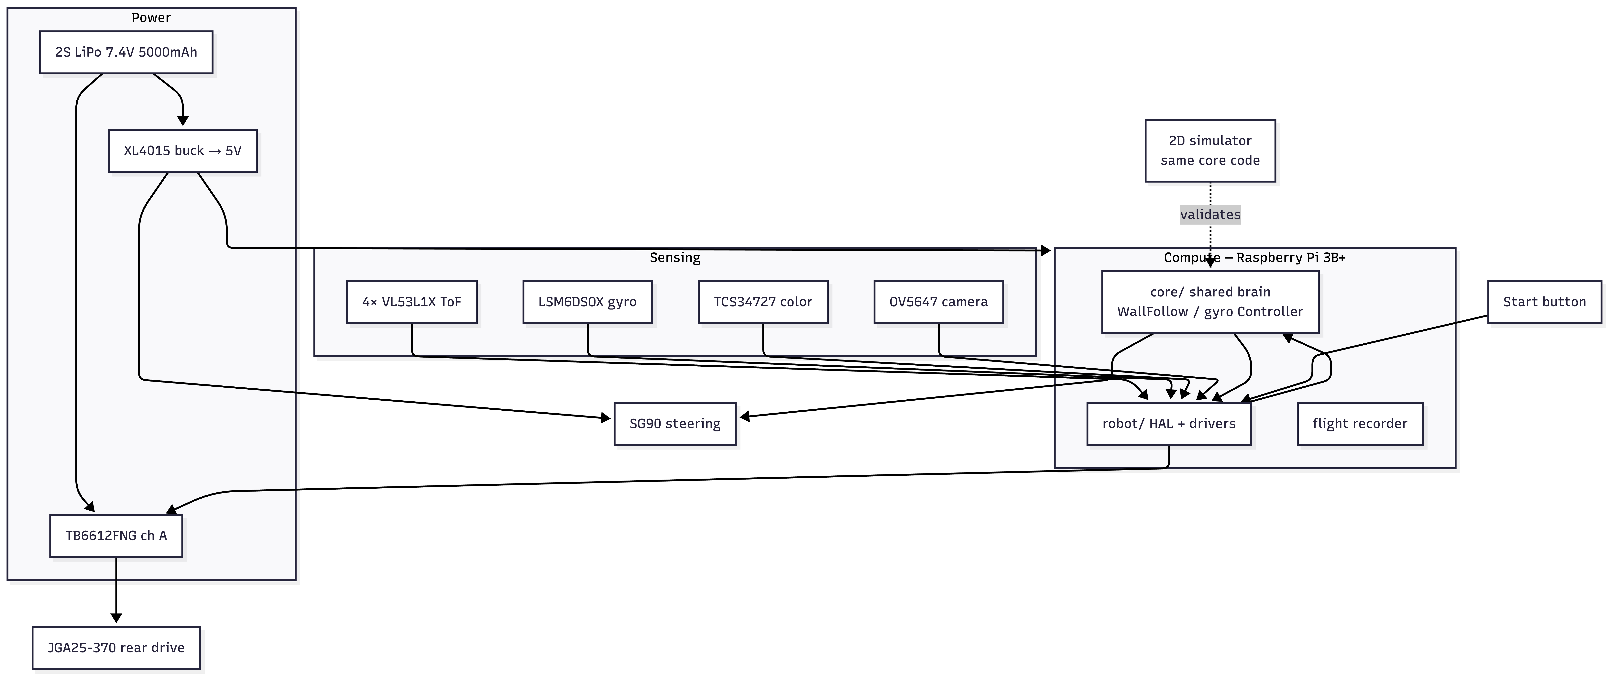
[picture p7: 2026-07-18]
docs/images/system-block-diagram.png

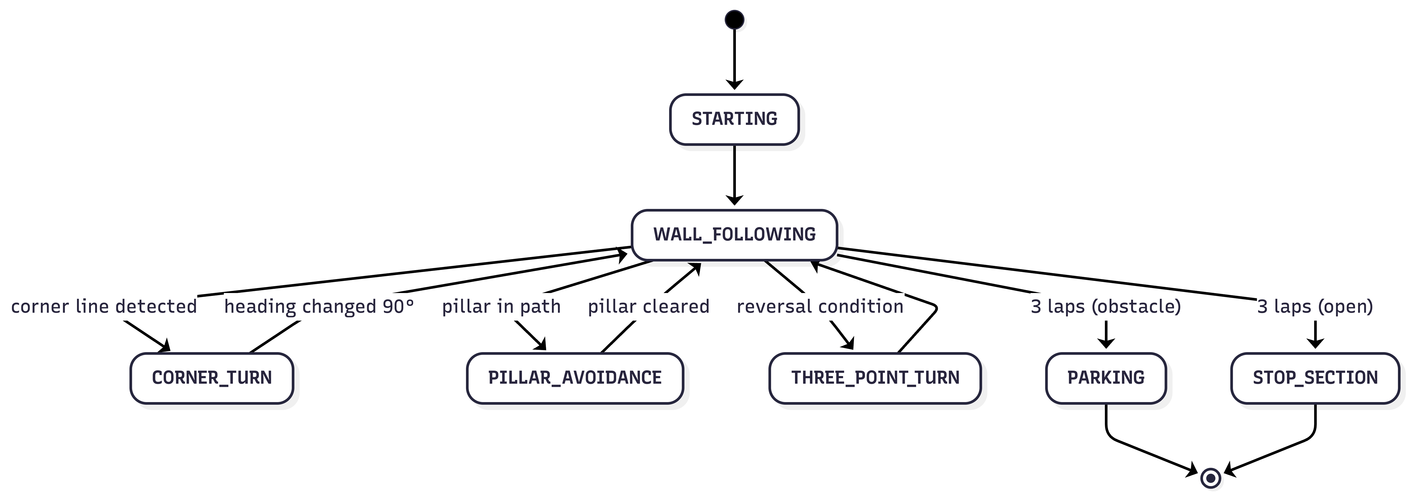
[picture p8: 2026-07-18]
docs/images/state-machine.png

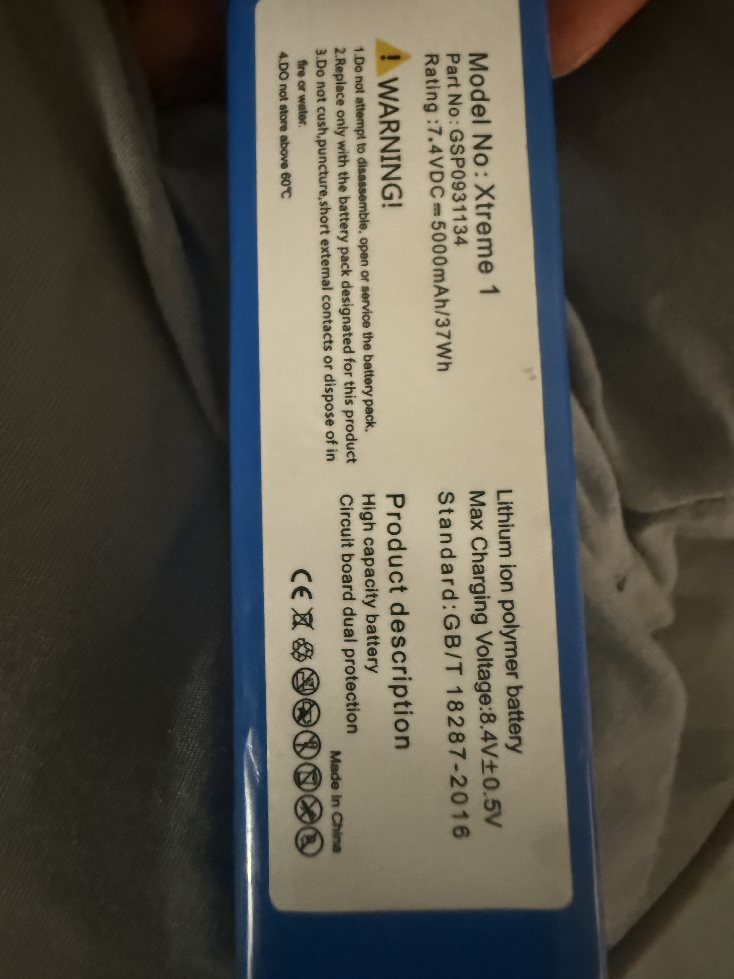
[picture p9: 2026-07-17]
docs/images/battery-2s-lipo-label.jpeg

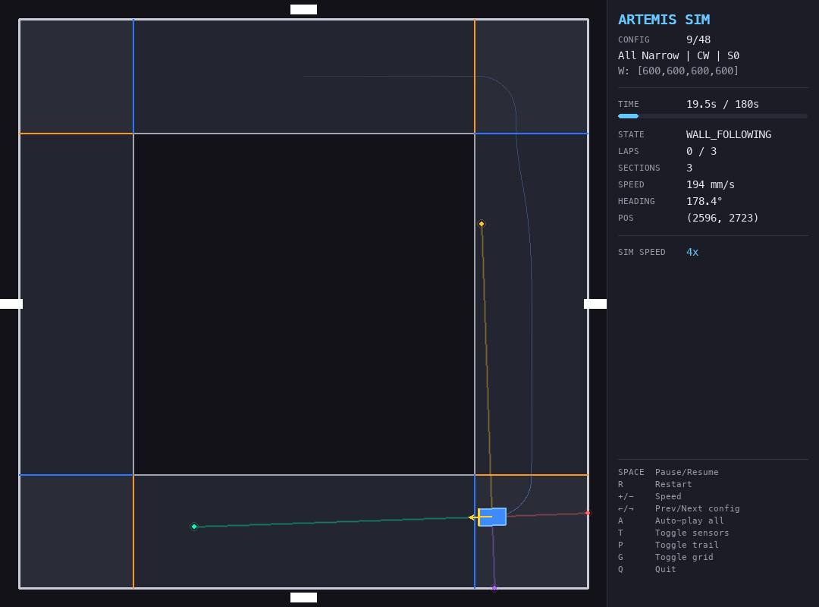
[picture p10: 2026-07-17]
screenshots/viewer_narrow.png

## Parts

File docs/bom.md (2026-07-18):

# Bill of Materials & Cost Report

Prices are estimates in Ghanaian cedis (GH₵) at time of purchase; sourcing links are representative searches, not endorsements. Items priced "tbc" were acquired later and their receipts are being collated.

## Current build

| Component | Qty | Est. unit price | Line total | Role |
|---|---:|---:|---:|---|
| [Raspberry Pi 3B+](https://www.aliexpress.com/wholesale?SearchText=raspberry+pi+3b%2B) | 1 | GH₵1,200.00 | GH₵1,200.00 | Main computer — control loop, vision, logging |
| [OV5647 camera, 160° wide-angle](https://www.aliexpress.com/wholesale?SearchText=OV5647+raspberry+pi+camera+160+degree) | 1 | GH₵108.00 | GH₵108.00 | Pillar detection (obstacle challenge), heading fusion |
| [JGA25-370 DC gearmotor, 12 V](https://www.aliexpress.com/wholesale?SearchText=jga25-370+12v+gear+motor) | 1 | GH₵108.00 | GH₵108.00 | Rear drive |
| [TB6612FNG motor driver](https://www.aliexpress.com/wholesale?SearchText=TB6612FNG+motor+driver) | 1 | GH₵72.00 | GH₵72.00 | H-bridge for the drive motor |
| [VL53L1X ToF sensor](https://www.aliexpress.com/w/wholesale-vl53l1x-tof-sensor.html) | 4 | GH₵48.00 | GH₵192.00 | Wall ranging (front/left/right/rear) |
| [XL4015 step-down converter](https://www.aliexpress.com/wholesale?SearchText=XL4015+step+down) | 1 | GH₵36.00 | GH₵36.00 | 5 V rail regulation |
| [SG90 servo (180°)](https://www.aliexpress.com/wholesale?SearchText=SG90+servo+motor) | 1 | GH₵30.00 | GH₵30.00 | Steering actuation |
| [TCS34725/27 color sensor](https://www.aliexpress.com/wholesale?SearchText=TCS34725+color+sensor) | 1 | GH₵26.00 | GH₵26.00 | Mat corner-line detection |
| [Power switch](https://www.aliexpress.com/wholesale?SearchText=rocker+switch) | 1 | GH₵12.00 | GH₵12.00 | Battery master switch |
| [Push button](https://www.aliexpress.com/wholesale?SearchText=momentary+push+button) | 1 | GH₵7.00 | GH₵7.00 | Round-start trigger (rules-required single interaction) |
| [LSM6DSOX IMU](https://www.aliexpress.com/wholesale?SearchText=LSM6DSOX) | 1 | tbc | tbc | Gyro heading (replacement — see below) |
| [2S LiPo pack, 7.4 V 5000 mAh, protected](https://www.aliexpress.com/wholesale?SearchText=2s+lipo+7.4v+5000mah) ([label](images/battery-2s-lipo-label.jpeg)) | 1 | tbc | tbc | Power supply (replacement — see below) |
| Gen-2 chassis (frame, steering, ⌀55 mm wheels) | 1 | tbc | tbc | Rolling chassis, built in-house |
| PLA filament for the printed body | ~0.3 kg | tbc | tbc | Tub + lid, printed on a Bambu Lab P1S |
| **Subtotal (priced items)** | | | **GH₵1,791.00** | |

## Parts bought and retired during development

Real iteration has a bill too. These parts were purchased, used, and replaced — each replacement is documented in the [root README §4](../README.md#4-engineering-decisions-and-lessons):

| Component | Qty | Est. price | Why it was retired |
|---|---:|---:|---|
| "MPU6050" 10-DoF IMU | 1 | GH₵19.00 | Counterfeit — WHO_AM_I answered 0x98; replaced by the LSM6DSOX, and boot-time chip-ID verification added so this can't happen silently again |
| 3× 18650 pack + holder, ~12 V | 1 | GH₵120.00 | Replaced by the protected 2S LiPo brick: more capacity, built-in protection circuit, no spring contacts to bounce loose under vibration |
| LEGO wheels 55981C05 | 4 | GH₵0.00 | Generation-1 drive wheels (on hand); superseded by the gen-2 chassis's ⌀55 mm rubber wheels |
| **Retired subtotal** | | **GH₵139.00** | |

Not itemized: the gen-1 printed chassis/body filament, wiring, headers, standoffs, and M3 hardware (small consumables), and tools (3D printer access, soldering iron, multimeter) which the team did not purchase for this project.

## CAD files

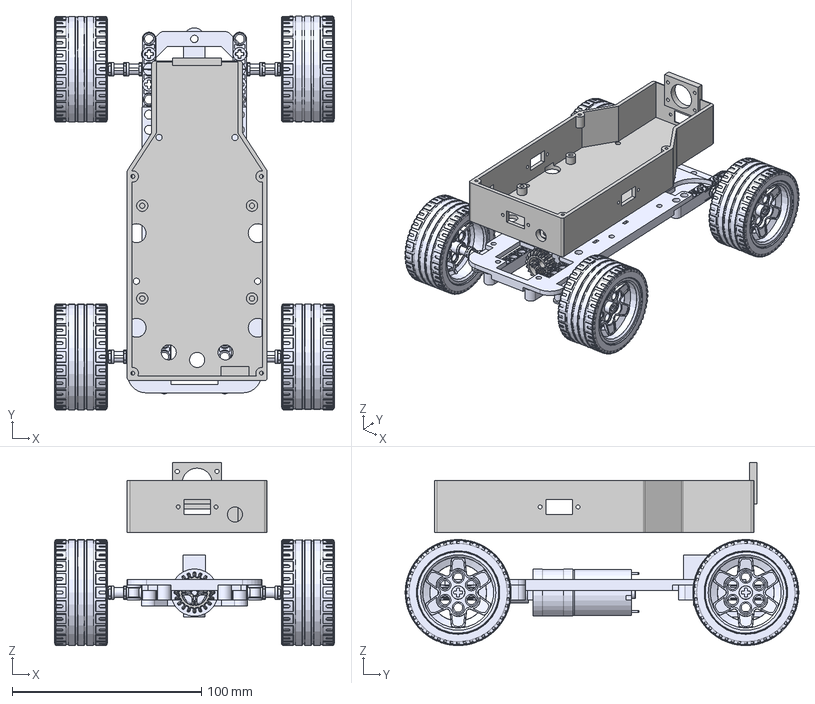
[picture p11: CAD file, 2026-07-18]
models/cad-source/New assembly test on new.step
148.0 x 208.0 x 96.8 mm
Improved frame
56908+41897-Rim_Tyre_Assembly(56x28) v1_1 x 4
7 holes_Výchozí x 4
diel20_Výchozí x 10
Diel3_Výchozí x 4
gear1_Výchozí
6mm Stainless Steel Hex Shaft Coupling
JGA25-370
SG90 Servo Motor_Predeterminado
Servo motor half horn
Steer connect
Steer shaft second
Support poles x 8
Ultrasonic mount
HCSR04 Ultrasonic Sensor x 3
Battery pack
Power board.step

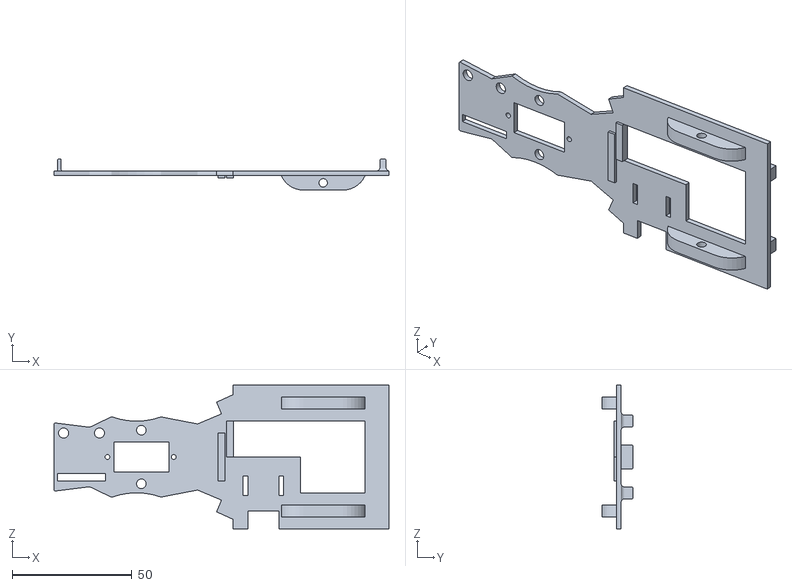
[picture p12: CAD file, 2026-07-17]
models/print/CHASIS.STL
140.0 x 13.0 x 60.0

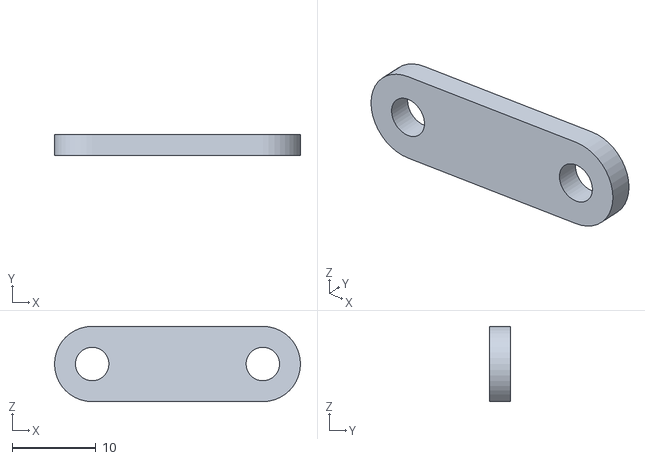
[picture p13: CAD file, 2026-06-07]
models/v1/ARM_LINKAGE.STL
29.4 x 2.50 x 9.00

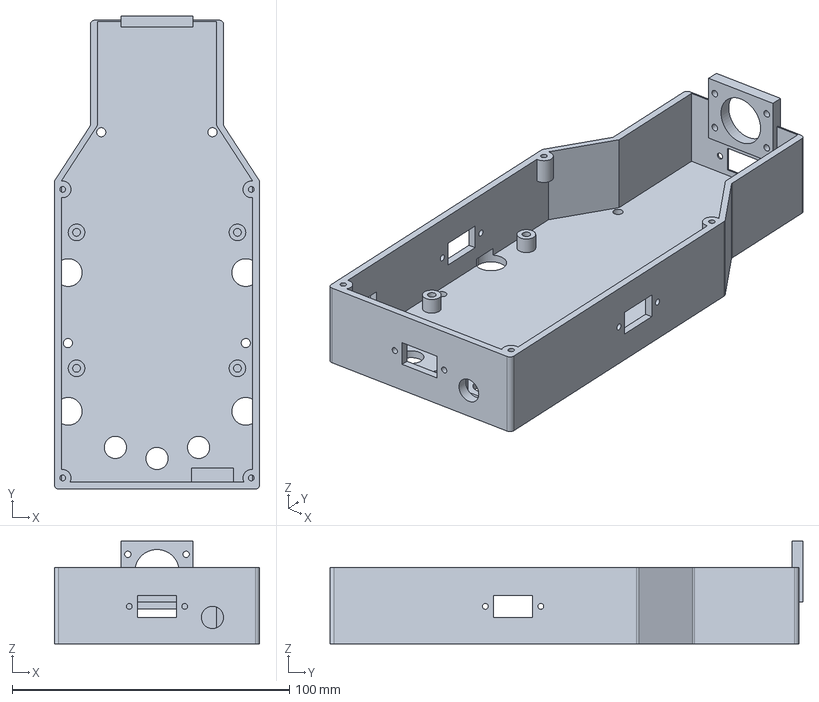
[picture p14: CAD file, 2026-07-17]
models/cad-source/body_tub.step
74.0 x 170.5 x 37.0 mm

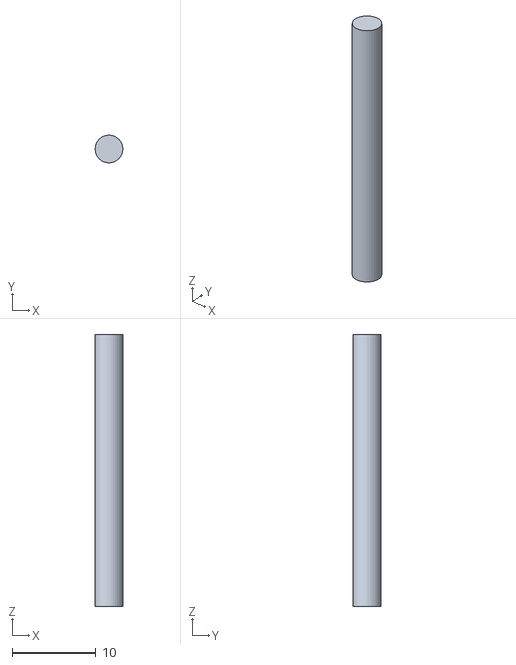
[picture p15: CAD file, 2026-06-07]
models/v1/AXLE.STL
3.30 x 3.30 x 32.4

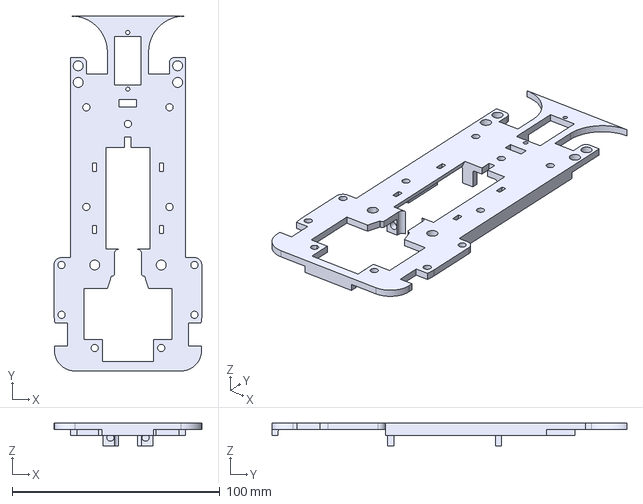
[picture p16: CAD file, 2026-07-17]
models/cad-source/Improved frame.step
71.2 x 171.1 x 11.0 mm

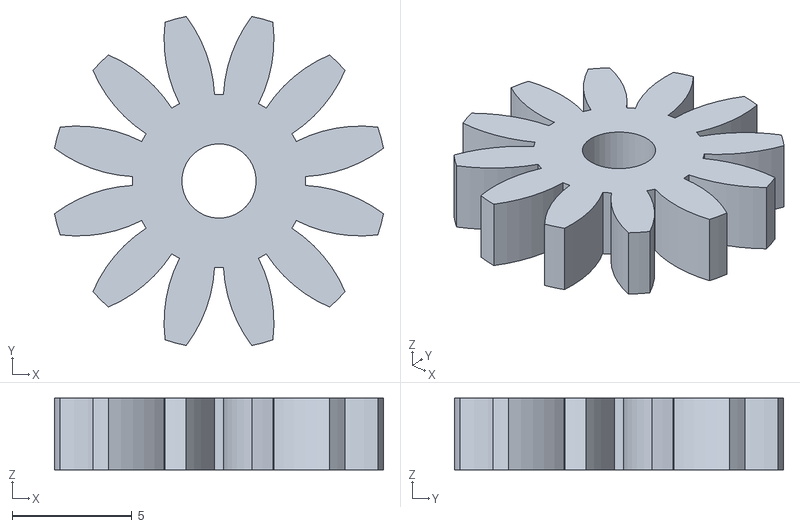
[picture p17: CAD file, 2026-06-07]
models/v1/GEAR_12.STL
13.7 x 13.7 x 3.00

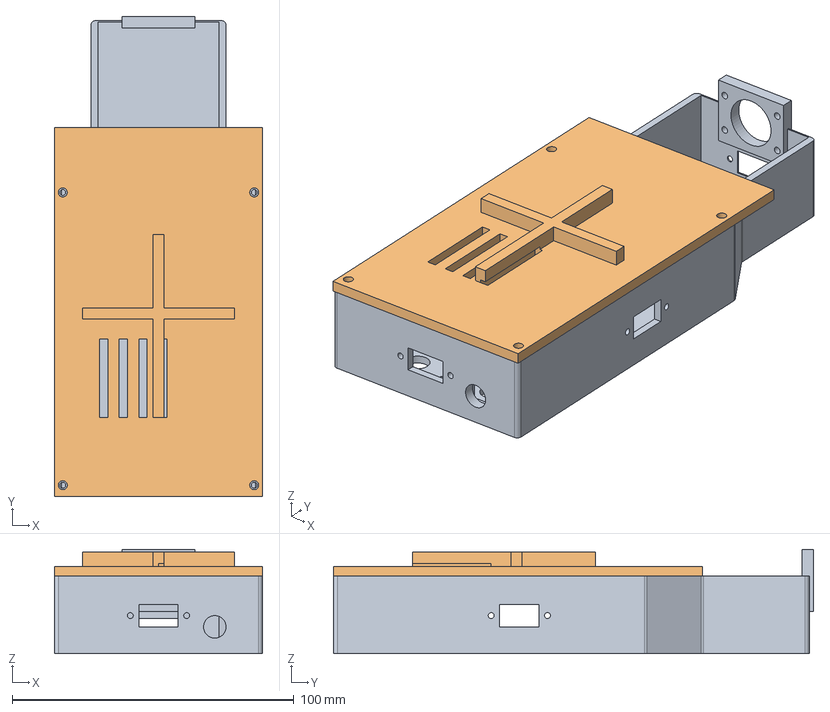
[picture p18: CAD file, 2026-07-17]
models/cad-source/body.step
74.0 x 170.5 x 37.0 mm

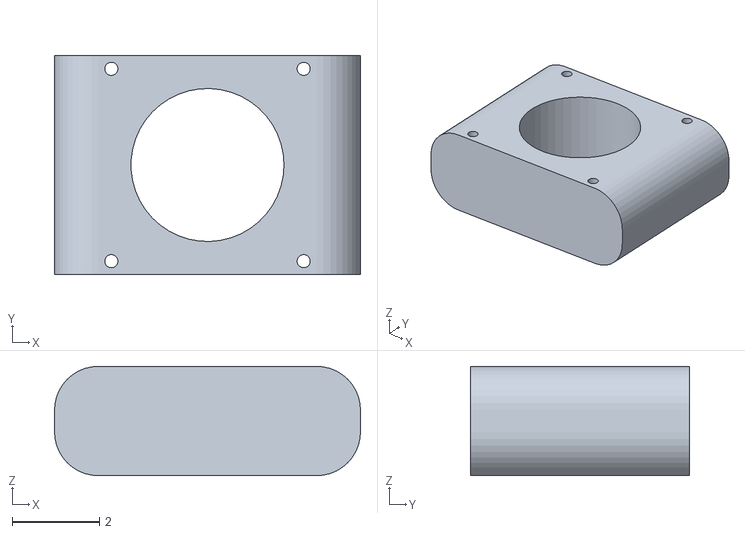
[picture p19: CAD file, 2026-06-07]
models/v1/CLIPPER.STL
7.00 x 5.00 x 2.50

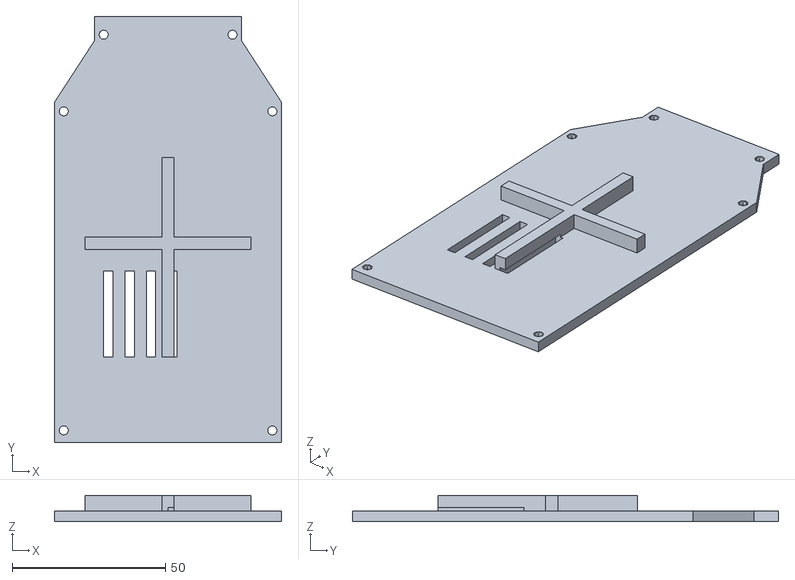
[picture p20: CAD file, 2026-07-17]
models/cad-source/body_lid_print.stl
74.0 x 139.0 x 8.50

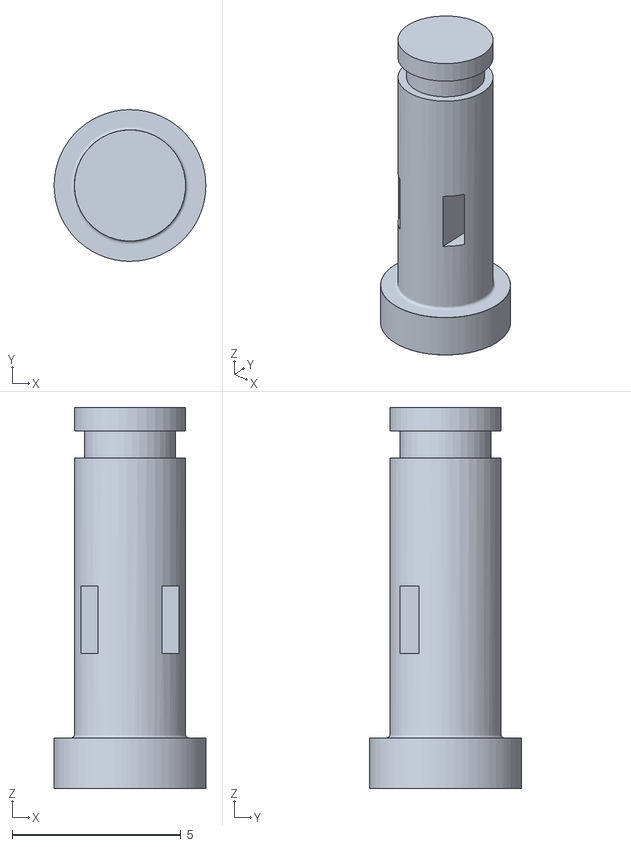
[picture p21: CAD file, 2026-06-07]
models/v1/CONNECTOR.STL
4.50 x 4.50 x 11.3

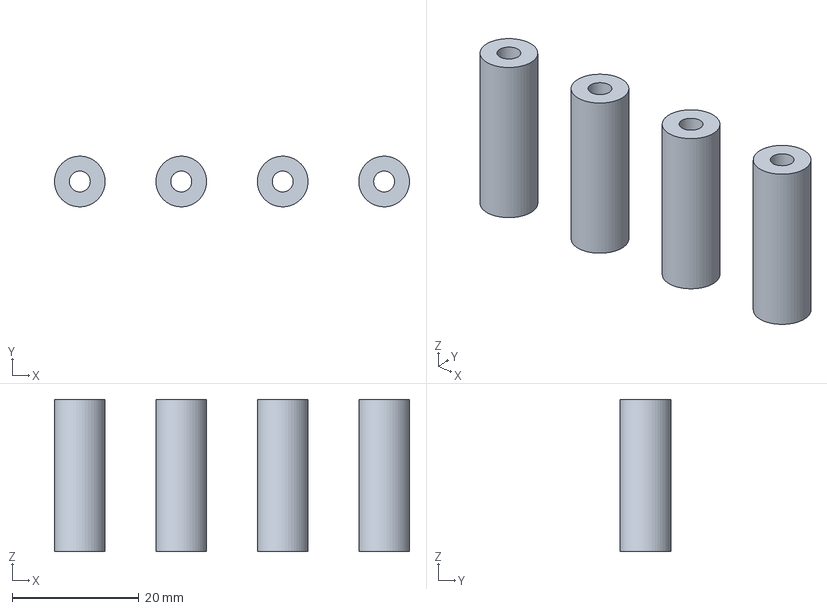
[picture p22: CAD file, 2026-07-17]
models/cad-source/legs.step
56.0 x 8.00 x 24.0 mm

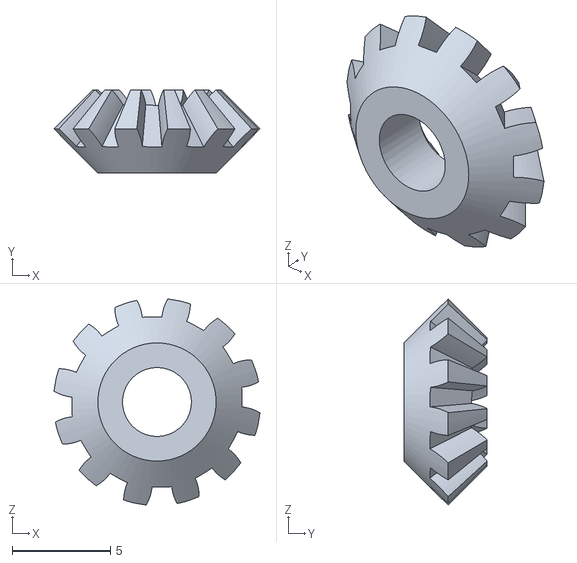
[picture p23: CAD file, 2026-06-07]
models/v1/BEVEL_GEAR.STL
10.5 x 4.24 x 10.5

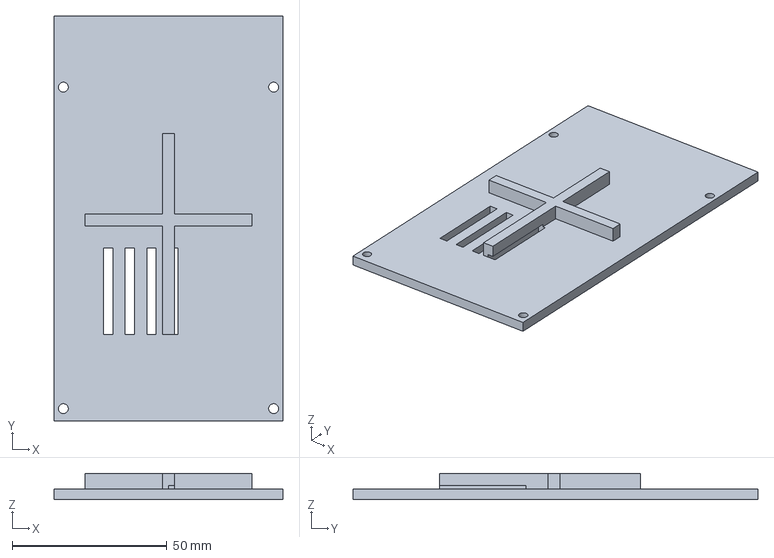
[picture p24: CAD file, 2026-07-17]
models/cad-source/body_lid.step
74.0 x 131.0 x 8.50 mm

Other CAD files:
models/v1/DRIVING_GEAR.STL
models/cad-source/body_tub_print.stl
models/v1/rim.STL
models/v1/AXLE_2.STL
models/cad-source/New assembly test on new.f3d
models/print/BODY.STL
models/print/body_lid.stl
models/print/body_tub.stl
models/print/body_tub_print.stl
models/print/legs.stl
models/v1/BODY.STL
models/v1/CHASIS.STL
models/v1/DRIVEN_GEAR_BOX.STL

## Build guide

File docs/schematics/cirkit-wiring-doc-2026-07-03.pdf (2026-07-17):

# Circuit Documentation

## Summary

This circuit is a complex system integrating various sensors, a motor driver, a servo motor, and a Raspberry Pi 3B+ as the central processing unit. The circuit is designed to control a motor and a servo, read data from multiple sensors, and manage power distribution efficiently. The Raspberry Pi interfaces with the components through GPIO pins, and the system is powered by a 12V battery with a step-down converter to provide necessary voltage levels for different components.

## Component List

1. TB6612FNG Motor Driver
- Description: A dual motor driver capable of controlling two DC motors with PWM input.
- Pins: GND, B01, B02, A02, A01, VCC, VM, PWMB, BI2, BI1, STBY, AI1, AI2, PWMA
2. SG90 Servo Motor
- Description: A small servo motor used for precise control of angular position.
- Pins: PWM, +5V, GND
3. ToF400C-VL53L1X (x4)
- Description: Time-of-Flight distance sensor for measuring distances.
- Pins: SHUT, INT, SCL, SDA, GND, VIN
4. XL4015 5A DC Buck Step-down
- Description: A step-down voltage converter to provide stable voltage output.
- Pins: Output +, Output -, Input +, Input -
5. TCS34725
- Description: A color sensor with an integrated IR filter and white LED.
- Pins: VIN, GND, 3.3V, SCL, SDA, INT, LED
6. 10 DOF IMU Sensor
- Description: An inertial measurement unit sensor for motion tracking.
- Pins: VCC, GND, SDA, SCL, INT, FSYNC
7. Pushbutton
- Description: A simple pushbutton switch for user input.
- Pins: Pin 2, Pin 1, Pin 3, Pin 4
8. Switch
- Description: A basic on/off switch for controlling power.
- Pins: Vin, GND, Vout
9. Resistor
- Description: A 10k Ohm resistor used for current limiting or pull-up/pull-down.
- Pins: pin1, pin2
10. Ceramic Capacitor (x2)
- Description: A 0.001 Farad capacitor for filtering and stabilization.
- Pins: pin0, pin1

11. Logic Level Shifter Converter Module
- Description: A module for shifting logic levels between different voltage domains.
- Pins: HV1, HV2, HV, GND, HV3, HV4, LV1, LV2, LV, LV3, LV4
12. Raspberry Pi 3B+
- Description: A single-board computer used as the main controller.
- Pins: Multiple GPIO pins, power pins, and communication interfaces.
13. Encoder Metal Gearmotor 12V DC High Speed 300RPM
- Description: A high-speed DC motor with an integrated encoder for feedback.
- Pins: Quad encoder B signal, Quad encoder A signal, Quad encoder +5V Vcc, Quad encoder Ground, Motor power terminal(-), Motor power terminal (+)
14. Battery 12V
- Description: A 12V battery used as the primary power source.
- Pins: +, -

## Wiring Details

### TB6612FNG Motor Driver

- GND: Connected to the common ground.
- B01: Connected to the Motor power terminal (+) of the Encoder Metal Gearmotor.
- B02: Connected to the Motor power terminal (-) of the Encoder Metal Gearmotor.
- STBY: Connected to GPIO 23 on the Raspberry Pi.
- BI1: Connected to GPIO 5 on the Raspberry Pi.
- BI2: Connected to GPIO 6 on the Raspberry Pi.
- PWMB: Connected to HV2 on the Logic Level Shifter Converter Module.
- VM: Connected to Vout on the Switch.
- VCC: Connected to the 5V Power from the Raspberry Pi.

### SG90 Servo Motor

- PWM: Connected to HV1 on the Logic Level Shifter Converter Module.
- +5V: Connected to the 5V Power from the Raspberry Pi.
- GND: Connected to the common ground.

### ToF400C-VL53L1X Sensors

- VIN: Connected to the 3.3V Power from the Raspberry Pi.
- GND: Connected to the common ground.
- SDA: Connected to GPIO 2 (I2C1 SDA) on the Raspberry Pi.
- SCL: Connected to GPIO 3 (I2C1 SCL) on the Raspberry Pi.
- SHUT: Connected to various GPIO pins on the Raspberry Pi for each sensor.

### XL4015 5A DC Buck Step-down

- Input +: Connected to Vin on the Switch.

- Input -: Connected to GND on the Switch.
- Output +: Connected to the 5V Power from the Raspberry Pi.
- Output -: Connected to the common ground.

### TCS34725

- VIN: Connected to the 3.3V Power from the Raspberry Pi.
- GND: Connected to the common ground.
- SDA: Connected to GPIO 2 (I2C1 SDA) on the Raspberry Pi.
- SCL: Connected to GPIO 3 (I2C1 SCL) on the Raspberry Pi.

### 10 DOF IMU Sensor

- VCC: Connected to Pin 1 of the Pushbutton.
- GND: Connected to the common ground.
- SDA: Connected to GPIO 2 (I2C1 SDA) on the Raspberry Pi.
- SCL: Connected to GPIO 3 (I2C1 SCL) on the Raspberry Pi.

### Pushbutton

- Pin 1: Connected to VCC of the 10 DOF IMU Sensor.
- Pin 3: Connected to pin1 of the Resistor and GPIO 17 on the Raspberry Pi.

### Switch

- Vin: Connected to the positive terminal of the Battery 12V.
- GND: Connected to the negative terminal of the Battery 12V and common ground.
- Vout: Connected to VM on the TB6612FNG Motor Driver.

### Resistor

- pin1: Connected to Pin 3 of the Pushbutton.
- pin2: Connected to GND on the Raspberry Pi.

### Ceramic Capacitors

- pin0: Connected to the 5V Power from the Raspberry Pi.
- pin1: Connected to the common ground.

### Logic Level Shifter Converter Module

- HV: Connected to the 5V Power from the Raspberry Pi.
- GND: Connected to the common ground.
- LV: Connected to the 3.3V Power from the Raspberry Pi.
- LV1: Connected to GPIO 18 (PCM CLK) on the Raspberry Pi.
- LV2: Connected to GPIO 13 (PWM1) on the Raspberry Pi.

### Raspberry Pi 3B+

- GPIO 2 (I2C1 SDA): Connected to SDA of the sensors.
- GPIO 3 (I2C1 SCL): Connected to SCL of the sensors.
- GPIO 5: Connected to BI1 on the TB6612FNG Motor Driver.
- GPIO 6: Connected to BI2 on the TB6612FNG Motor Driver.
- GPIO 13 (PWM1): Connected to LV2 on the Logic Level Shifter Converter Module.
- GPIO 17: Connected to Pin 3 of the Pushbutton.
- GPIO 18 (PCM CLK): Connected to LV1 on the Logic Level Shifter Converter Module.
- GPIO 23: Connected to STBY on the TB6612FNG Motor Driver.
- GPIO 24: Connected to Quad encoder B signal of the Encoder Metal Gearmotor.
- GPIO 25: Connected to SHUT of one ToF400C-VL53L1X sensor.
- GPIO 26: Connected to SHUT of another ToF400C-VL53L1X sensor.
- 5V Power: Connected to VCC of the TB6612FNG Motor Driver and +5V of the SG90 Servo Motor.
- 3.3V Power: Connected to VIN of the ToF400C-VL53L1X sensors and TCS34725.

### Encoder Metal Gearmotor 12V DC High Speed 300RPM

- Quad encoder +5V Vcc: Connected to Pin 1 of the Pushbutton.
- Quad encoder Ground: Connected to the common ground.
- Motor power terminal (+): Connected to B01 on the TB6612FNG Motor Driver.
- Motor power terminal (-): Connected to B02 on the TB6612FNG Motor Driver.

### Battery 12V

- +: Connected to Vin on the Switch.
- -: Connected to GND on the Switch.

## Documented Code

import RPi.GPIO as GPIO
import time

# Pins

AIN1 = 17
AIN2 = 27
PWMA = 22
STBY = 23

GPIO.setmode(GPIO.BCM)
GPIO.setup(AIN1, GPIO.OUT) GPIO.setup(AIN2, GPIO.OUT) GPIO.setup(PWMA, GPIO.OUT) GPIO.setup(STBY, GPIO.OUT)

# Enable driver

GPIO.output(STBY, GPIO.HIGH)

# PWM setup

pwm = GPIO.PWM(PWMA, 1000) # 1kHz PWM pwm.start(0)

# Forward at 70% speed

GPIO.output(AIN1, GPIO.HIGH) GPIO.output(AIN2, GPIO.LOW) pwm.ChangeDutyCycle(70)
time.sleep(5)

# Reverse at 50% speed

GPIO.output(AIN1, GPIO.LOW) GPIO.output(AIN2, GPIO.HIGH) pwm.ChangeDutyCycle(50)
time.sleep(5)

# Stop motor

GPIO.output(AIN1, GPIO.LOW) GPIO.output(AIN2, GPIO.LOW) pwm.ChangeDutyCycle(0)
GPIO.output(STBY, GPIO.LOW)

GPIO.cleanup()

This code is designed to control a motor using the TB6612FNG Motor Driver connected to a Raspberry Pi. It sets up the GPIO pins, enables the motor driver, and uses PWM to control the motor speed and direction. The motor runs forward at 70% speed, then reverses at 50% speed, and finally stops.

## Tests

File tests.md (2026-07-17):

# Testing Workflow

Every control change follows the same three-stage pipeline: **simulate → bench → field**. Nothing drives the robot that hasn't passed the sim suites, and nothing joins the control loop that hasn't been bench-tested in isolation.

## Stage 1 — Simulation suites

The simulator ([`src/sim/open-challenge-sim/`](src/sim/open-challenge-sim)) shares the *actual* control code in [`src/core/`](src/core) — the tests exercise the same classes the robot runs, not a reimplementation.

Run from `src/sim/open-challenge-sim/` (needs Python 3.8+, `pygame`, `numpy` — see [`requirements.txt`](requirements.txt)):

| Suite | Command | What it verifies |
|---|---|---|
| PD stability | `python test_pd_tuning.py` | Three phases: straight-line PD convergence from an injected heading error; corner-exit stabilization; then the full 48-case placement/corner-entry matrix. **Pass bar: 48/48 finish 3 laps without wall contact.** |
| Rules scoring | `python test_open_score.py` | Scores complete `WallFollowController` runs exactly per the WRO rubric (24 section points + finish bonus). Ground truth comes from the sim's pose — the controller itself stays pose-free. **Pass bar: 30/30.** |
| Batch/headless | `python test_headless.py` | Graphics-free batch runner across randomized track configs — the harness the other suites build on; used in every tuning loop. |
| Sensor-noise regression | `python test_tof_noise.py` | Replays full open rounds under injected ToF dropout noise (bench-measured spike patterns) across filter configurations. This suite is how the ToF outlier-gate/median design was chosen — one candidate filter passed clean runs but scored 0/10 on the narrow track from filter lag, which only this suite exposed. |

The interactive viewer (`python sim_viewer.py`) is the debugging companion: pause, single-step, sensor-ray and path-trail overlays, and config switching across the randomized layouts.

**Regression rule:** a change to anything in `core/` requires re-running the PD and scoring suites before deployment. When a field failure is diagnosed, we first reproduce it in the sim (adding a config or noise case if needed), fix it in `core/`, and re-validate — so the sim's test matrix only ever grows.

## Stage 2 — Hardware bench tests

Each device has an isolated bring-up script in [`src/robot/bench/`](src/robot/bench), run before the device is trusted in the control loop and re-run after any rewiring:

| Script | Purpose |
|---|---|
| `i2c_scan` | Confirm every I2C device enumerates at its assigned address |
| `tof_test/` | Live per-sensor distance readout; hand-wave test verifies each sensor's label matches its axis (a mandatory step — mislabeled axes have burned us) |
| `imu_test`, `robot.turn90` | Drift measurement, bias calibration check, and mounted-sign verification via a commanded 90° turn |
| `servo_test/` | Jog the linkage to record real pulse-width limits and center |
| `motor_test/` | Graduated probes (passive GPIO probe → single-channel spin → full driver) that isolate chip vs wiring vs code faults |
| `button_test` | Start-button wiring and edge detection |
| `power_watch/` | Continuous under-voltage/throttling logger (runs as a service, not just at the bench) |

Verified values graduate from `VERIFY`-marked guesses to constants in [`src/robot/hardware_config.py`](src/robot/hardware_config.py); `grep VERIFY src/robot/hardware_config.py` lists exactly what still runs unmeasured.

## Stage 3 — Field runs with the flight recorder

Every real run is automatically logged by [`src/robot/run_logger.py`](src/robot/run_logger.py):

- `sensors.csv` — full sensor state at 30 Hz
- `camera.jsonl` — detections at 10 Hz, plus keyframe JPEGs on every detection change
- `meta.json` — run mode, parameters, and the **deployed git revision**, so any log is traceable to the exact code that produced it

Post-run analysis: `python3 -m robot.bench.log_timeline <run-dir>` renders the run as an event timeline with an ASCII plot of the driven path — how we do post-mortems on field behaviour without a camera crew. Logs are pulled off the Pi with `rsync` and kept per-run.

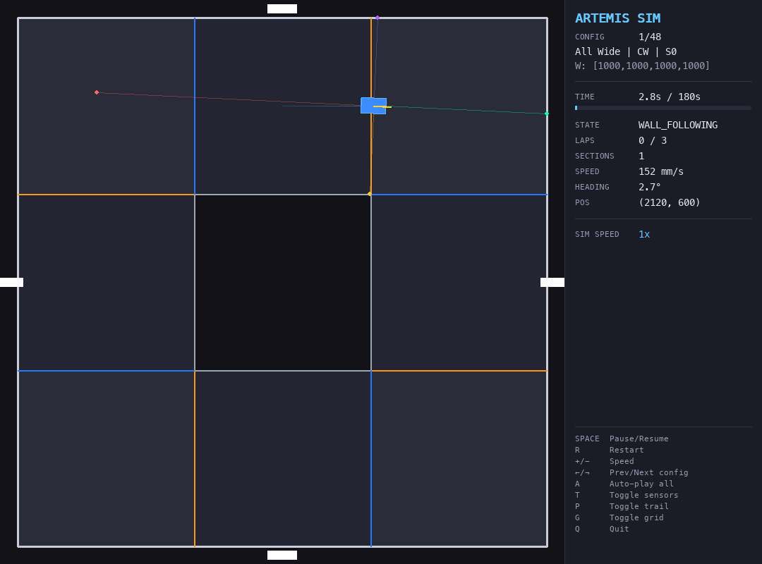
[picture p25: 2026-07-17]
screenshots/viewer_test.png

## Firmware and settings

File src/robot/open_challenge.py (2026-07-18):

"""Open-challenge run — real-robot entry point. On the Pi:

    python -m robot.open_challenge                     # ToF-only (default mode)
    python -m robot.open_challenge --mode fusion       # ToF + camera (heading fusion
                                                       #  + line colour for direction)
    python -m robot.open_challenge --mode imu --direction cw
                                                       # gyro heading-hold Controller
                                                       #  (requires a healthy IMU)
    common flags:
      --now          skip the start button, 3-2-1 countdown
      --width 600    narrow track (default 1000mm)

MODES
  tof     WallFollowController on the four ToF sensors alone. The proven
          baseline: 30/30 sim score, no camera, no IMU.
  fusion  Same controller + CameraWorker: the camera adds an absolute
          wall-base heading (blended 0.7 ToF / 0.3 vision) and orange/blue
          line detection, which locks the driving direction by rule (orange
          first = CW) instead of the geometric guess. Do NOT run the web
          dashboard's camera at the same time (one Picamera2 owner only —
          stop artemis-web or export ARTEMIS_NO_CAMERA=1 for it).
  imu     The primary gyro brain (core.controller.Controller): heading-hold
          PID, corner = target_heading += 90 on the corner line colour.
          Contingency for a trustworthy IMU (e.g. a 9-axis drift-corrected
          unit). Uses the camera for line detection (no colour sensor) and a
          dead-reckoned pose shim for the controller's line-dedup distance.
          --direction cw|ccw is required: the corner-entry colour depends on
          it (auto-detection from the first line is a TODO).
"""

import argparse
import math
import time

from core.config import CONTROL_HZ, MAX_SPEED, TRACK_WIDTH_OPEN_WIDE
from core.wall_follow_controller import WallFollowController, WFState
from robot.hal import RealHardware
from robot.start_button import arm_start, wait_for_start_button  # noqa: F401


class OpenChallengeWorld:
    """Minimal `track` stand-in — controllers only ask for the width."""

    def __init__(self, track_width: float):
        self.challenge_type = "open"
        self.track_width = track_width

    def get_local_track_width(self, x: float, y: float) -> float:
        return self.track_width


class DeadReckonedPose:
    """Pose shim for the gyro Controller (imu mode).

    Controller.update() reads robot.x/y (only to measure distance between
    line detections) and robot.distance_traveled (parking, unused in open).
    Without an encoder, integrate the COMMANDED speed along the IMU heading —
    plenty for a 200mm line-dedup radius. Motor/servo calls pass through to
    the real hardware.
    """

    def __init__(self, hw):
        self._hw = hw
        self.x = 0.0
        self.y = 0.0
        self.distance_traveled = 0.0
        self._speed_cmd = 0.0

    def integrate(self, heading_deg: float, dt: float):
        v = self._speed_cmd * MAX_SPEED
        self.x += v * math.cos(math.radians(heading_deg)) * dt
        self.y += v * math.sin(math.radians(heading_deg)) * dt
        self.distance_traveled += abs(v) * dt

    def set_speed(self, fraction: float):
        self._speed_cmd = fraction
        self._hw.set_speed(fraction)

    def set_steering(self, angle: float):
        self._hw.set_steering(angle)

    def stop(self):
        self._speed_cmd = 0.0
        self._hw.stop()


def _make_logger(enabled: bool, challenge: str, mode: str, meta: dict,
                 save_frames: bool = True):
    """RunLogger or None. Never let a logging failure abort a run."""
    if not enabled:
        return None
    try:
        from robot.run_logger import RunLogger
        return RunLogger(challenge, mode, meta=meta, save_frames=save_frames)
    except Exception as exc:
        print(f"[logger] disabled — could not start ({exc})")
        return None


def run_wall_follow(track_width: float, wait_button: bool, use_camera: bool,
                    log: bool = True) -> None:
    """tof / fusion modes: WallFollowController, optionally camera-augmented."""
    hw = RealHardware(use_camera=False, use_imu=False, use_color=False)
    camera = None
    if use_camera:
        from robot.camera_worker import CameraWorker
        camera = CameraWorker()
        print(f"CameraWorker: {'live' if camera.available else 'UNAVAILABLE (ToF-only fallback)'}")
    world = OpenChallengeWorld(track_width)
    controller = WallFollowController(track_width=track_width)

    if not arm_start(wait_button):
        hw.close()
        return
    print("GO")

    logger = _make_logger(log, "open", "fusion" if use_camera else "tof",
                          {"track_width": track_width})
    if logger and camera is not None:
        camera.logger = logger

    dt = 1.0 / CONTROL_HZ
    try:
        while controller.state != WFState.STOPPED:
            tick_start = time.monotonic()
            sensors = hw.read_sensors()
            cam_line = cam_heading = None
            if camera is not None and camera.available:
                cam_heading = camera.vision_heading
                cam_line = camera.line_color
                sensors.vision_heading = cam_heading
                sensors.color_detected = cam_line
            controller.update(sensors, hw, world, dt)
            if logger:
                logger.log_sensors(sensors, hw.servo_angle, hw.motor_speed,
                                   controller.get_state_name(), controller.turns,
                                   cam_line, cam_heading)
            elapsed = time.monotonic() - tick_start
            if elapsed < dt:
                time.sleep(dt - elapsed)  # hold the control rate
    except KeyboardInterrupt:
        pass
    finally:
        hw.stop()
        if camera is not None:
            camera.logger = None
            camera.close()
        hw.close()
        if logger:
            logger.close({"final_state": controller.get_state_name(),
                          "turns": controller.turns,
                          "elapsed_s": round(controller.elapsed_time, 1)})
        print(f"Done — state={controller.get_state_name()} "
              f"turns={controller.turns} t={controller.elapsed_time:.1f}s")


def run_gyro(track_width: float, wait_button: bool, direction: int,
             log: bool = True) -> None:
    """imu mode: the primary gyro Controller (needs a healthy IMU + camera lines)."""
    from core.controller import Controller, State
    from robot.camera_worker import CameraWorker

    hw = RealHardware(use_camera=False, use_imu=True, use_color=False)
    camera = CameraWorker()
    if not camera.available:
        print("CameraWorker UNAVAILABLE — corner lines will not trigger; "
              "IMU mode needs the camera for line detection")
    pose = DeadReckonedPose(hw)
    world = OpenChallengeWorld(track_width)
    controller = Controller(driving_direction=direction, challenge_type='open')

    if not arm_start(wait_button):
        hw.close()
        return
    print("GO")

    logger = _make_logger(log, "open", "imu",
                          {"track_width": track_width,
                           "direction": "cw" if direction == 1 else "ccw"})
    if logger:
        camera.logger = logger

    dt = 1.0 / CONTROL_HZ
    try:
        while controller.state not in (State.FINISHED, State.STOPPED):
            tick_start = time.monotonic()
            sensors = hw.read_sensors()
            cam_line = camera.line_color if camera.available else None
            if cam_line is not None:
                sensors.color_detected = cam_line
            controller.update(sensors, pose, world, dt)
            pose.integrate(sensors.imu_heading, dt)
            if logger:
                logger.log_sensors(sensors, hw.servo_angle, hw.motor_speed,
                                   controller.state.name, controller.sections_passed,
                                   cam_line, camera.vision_heading if camera.available else None)
            elapsed = time.monotonic() - tick_start
            if elapsed < dt:
                time.sleep(dt - elapsed)
    except KeyboardInterrupt:
        pass
    finally:
        pose.stop()
        camera.logger = None
        camera.close()
        hw.close()
        if logger:
            logger.close({"final_state": controller.state.name,
                          "laps": controller.laps_completed,
                          "sections": controller.sections_passed,
                          "elapsed_s": round(controller.elapsed_time, 1)})
        print(f"Done — state={controller.state.name} laps={controller.laps_completed} "
              f"sections={controller.sections_passed} t={controller.elapsed_time:.1f}s")


def run_imu_fusion(track_width: float, wait_button: bool, log: bool = True) -> None:
    """imufusion mode: IMU heading-hold + ToF-detected, gyro-executed 90° turns,
    camera for direction. The recommended real-robot open-challenge driver."""
    from core.imu_fusion_controller import ImuFusionController, IFState
    from robot.camera_worker import CameraWorker

    hw = RealHardware(use_camera=False, use_imu=True, use_color=False)
    camera = CameraWorker()
    print(f"CameraWorker: {'live' if camera.available else 'UNAVAILABLE (geometry-only direction)'}")
    world = OpenChallengeWorld(track_width)
    controller = ImuFusionController(track_width=track_width)

    if not arm_start(wait_button):
        hw.close()
        return
    print("GO")
    hw.imu.reset_heading(0.0)   # heading reference = 0 at GO

    logger = _make_logger(log, "open", "imufusion", {"track_width": track_width})
    if logger:
        camera.logger = logger

    dt = 1.0 / CONTROL_HZ
    try:
        while controller.state != IFState.STOPPED:
            tick_start = time.monotonic()
            sensors = hw.read_sensors()          # carries the real imu_heading
            cam_line = camera.line_color if camera.available else None
            if cam_line is not None:
                sensors.color_detected = cam_line
            controller.update(sensors, hw, world, dt)
            if logger:
                logger.log_sensors(sensors, hw.servo_angle, hw.motor_speed,
                                   controller.get_state_name(), controller.turns,
                                   cam_line, camera.vision_heading if camera.available else None)
            elapsed = time.monotonic() - tick_start
            if elapsed < dt:
                time.sleep(dt - elapsed)
    except KeyboardInterrupt:
        pass
    finally:
        hw.stop()
        if logger:
            camera.logger = None
        camera.close()
        hw.close()
        if logger:
            logger.close({"final_state": controller.get_state_name(),
                          "turns": controller.turns,
                          "elapsed_s": round(controller.elapsed_time, 1)})
        print(f"Done — state={controller.get_state_name()} "
              f"turns={controller.turns} t={controller.elapsed_time:.1f}s")


def run_color_imu(track_width: float, wait_button: bool, log: bool = True) -> None:
    """color mode: the downward COLOUR sensor triggers turns (orange=right,
    blue=left), ToF confirms the corner, the IMU executes a clean 90°. No camera
    (that's obstacle-only). Direction auto-detects from the first line crossed."""
    from core.color_imu_controller import ColorImuController, CIState
    from robot.color_worker import ColorWorker

    hw = RealHardware(use_camera=False, use_imu=True, use_color=False)
    color = ColorWorker()   # owns the sensor; reads fast + latches brief crossings
    print(f"ColorWorker: {'live' if color.available else 'UNAVAILABLE'}")
    world = OpenChallengeWorld(track_width)
    controller = ColorImuController(track_width=track_width)

    if not arm_start(wait_button):
        color.close()
        hw.close()
        return
    print("GO")
    hw.imu.reset_heading(0.0)

    logger = _make_logger(log, "open", "color", {"track_width": track_width})
    dt = 1.0 / CONTROL_HZ
    try:
        while controller.state != CIState.STOPPED:
            tick_start = time.monotonic()
            sensors = hw.read_sensors()   # imu_heading + ToFs
            sensors.color_detected = color.color   # latched line colour
            controller.update(sensors, hw, world, dt)
            if logger:
                logger.log_sensors(sensors, hw.servo_angle, hw.motor_speed,
                                   controller.get_state_name(), controller.turns,
                                   sensors.color_detected, None)
            elapsed = time.monotonic() - tick_start
            if elapsed < dt:
                time.sleep(dt - elapsed)
    except KeyboardInterrupt:
        pass
    finally:
        hw.stop()
        color.close()
        hw.close()
        if logger:
            logger.close({"final_state": controller.get_state_name(),
                          "turns": controller.turns,
                          "elapsed_s": round(controller.elapsed_time, 1)})
        print(f"Done — state={controller.get_state_name()} "
              f"turns={controller.turns} t={controller.elapsed_time:.1f}s")


def _web_app_running() -> bool:
    """True if artemis-web answers on :8000 — it owns the camera AND the ToFs
    (constructing our own TofArray would reset them under it, and two owners
    corrupt reads mid-run), so competition runs must not start alongside it."""
    import socket
    try:
        with socket.create_connection(("127.0.0.1", 8000), timeout=0.5):
            return True
    except OSError:
        return False


def main() -> None:
    parser = argparse.ArgumentParser(description="WRO open-challenge run.")
    parser.add_argument("--mode", choices=("tof", "fusion", "imu", "imufusion", "color"),
                        default="tof",
                        help="tof = ToF-only wall-follower (default); fusion = + camera "
                             "heading/lines; imu = gyro heading-hold Controller; "
                             "imufusion = IMU-executed turns, ToF-detected, camera "
                             "for direction (recommended)")
    parser.add_argument("--now", action="store_true",
                        help="skip the start button; 3-2-1 countdown instead")
    parser.add_argument("--width", type=float, default=TRACK_WIDTH_OPEN_WIDE,
                        help="track width in mm (default 1000; use 600 for narrow)")
    parser.add_argument("--direction", choices=("cw", "ccw"),
                        help="imu mode only: driving direction (sets corner-entry colour)")
    parser.add_argument("--no-log", action="store_true",
                        help="disable the run flight-recorder (~/artemis/logs/)")
    args = parser.parse_args()

    if _web_app_running():
        parser.error("artemis-web is running — it owns the camera and ToFs. "
                     "Stop it first: sudo systemctl stop artemis-web")

    log = not args.no_log
    if args.mode == "imu":
        if not args.direction:
            parser.error("--mode imu requires --direction cw|ccw")
        run_gyro(args.width, not args.now, 1 if args.direction == "cw" else -1, log=log)
    elif args.mode == "imufusion":
        run_imu_fusion(args.width, not args.now, log=log)
    elif args.mode == "color":
        run_color_imu(args.width, not args.now, log=log)
    else:
        run_wall_follow(args.width, not args.now,
                        use_camera=(args.mode == "fusion"), log=log)


if __name__ == "__main__":
    main()

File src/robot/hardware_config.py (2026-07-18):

"""Hardware config for this build: GPIO pins, I2C addresses, calibration.

Tuned control/physics constants live in core.config (shared with the sim) — keep
them out of here so wiring changes never touch them. Anything marked VERIFY is a
guess from the BOM/CAD for now — we'll verify it on the actual robot.
"""

# BCM pin numbers, not physical header pins.
GPIO_MODE = "BCM"


# Drive motor — 12V 300RPM gearmotor via a TB6612FNG H-bridge.
# Uses CHANNEL A (channel B confirmed dead at chip level, 2026-07): motor leads
# on A01/A02, driver inputs on PWMA/AIN1/AIN2. The Pi-side GPIOs are unchanged
# from the old channel-B wiring — only the TB6612 terminals moved. Level shifter
# removed 2026-07-13 — logic driven direct from 3.3V GPIO (TB6612 VIH>=2.0V).
class Motor:
    PIN_PWM = 13      # PWMA (hardware PWM pin) — pin 33
    PIN_IN1 = 12      # AIN1 (direction) — pin 32 (moved off GPIO5: dead breadboard jumper)
    PIN_IN2 = 6       # AIN2 (direction) — pin 31
    # STBY is hardwired to 3.3V (pin 17) on the bench build — the GPIO23 route had
    # a dead jumper. Chip is always enabled; the GPIO23 write below is a harmless
    # no-op. Rewire to a GPIO if you need software enable/disable.
    PIN_STBY = 23     # STBY (not connected; hardwired 3.3V) — see note above
    PIN_ENC_A = None  # VERIFY — schematic only shows encoder B wired
    PIN_ENC_B = 24    # encoder ch B
    PWM_FREQUENCY_HZ = 1000  # VERIFY

    OUTPUT_RPM = None              # VERIFY measured RPM at the wheel
    ENCODER_COUNTS_PER_REV = None  # VERIFY counts per output rev
    # Top-speed cap, compresses the fraction->duty range (real-robot only; the sim
    # has no deadband). History 2026-07-18: 1.0 crashed corners (too fast) -> 0.62
    # fixed cornering but cruise (~49% duty) then STALLED on the straight (front
    # ToF froze mid-corridor, imufusion run held heading 90s but stopped moving).
    # 0.78 keeps corners controllable while lifting cruise clear of the static-
    # friction break.
    MAX_PWM_DUTY = 0.78
    # Deadband floor: below this PWM duty the gen-2 chassis doesn't move (it only
    # "crawled" at 0.35, and stalled from rest around ~0.49-0.53 on the mat). The
    # fraction remaps onto [MOTOR_MIN_DUTY, MAX_PWM_DUTY] so the slowest speed is
    # still comfortably above the break. TUNE on the mat: raise if it still stalls,
    # lower if the slowest speed is too fast to corner cleanly.
    MOTOR_MIN_DUTY = 0.48


# Steering servo.
class Servo:
    PIN_SIGNAL = 18   # via level shifter LV1->HV1 (hardware PWM pin)
    MODEL = "SG90"
    # Pulse widths (us): CENTER = wheels straight; MIN/MAX = pulse at full
    # LEFT/RIGHT throw (i.e. at -/+ MAX_STEERING_ANGLE = 35 deg).
    # Placeholders — jog the real linkage and record these.
    PULSE_CENTER_US = 1500
    PULSE_MIN_US = 1000
    PULSE_MAX_US = 2000
    DIRECTION = 1     # flip if positive steering turns the wrong way. VERIFY.
    # Steering slew rate (deg/s): how fast the wheels sweep toward a new
    # target. Full lock-to-lock (70 deg) takes 70/SLEW_RATE_DPS seconds.
    SLEW_RATE_DPS = 90.0
    # Steering limit is core.config.MAX_STEERING_ANGLE (35°, measured throw).


# ToF distance sensors.
# NOTE: the Pi's I2C bus is set to 50 kHz (dtparam=i2c_arm_baudrate=50000 in
# /boot/firmware/config.txt) — at the default 100 kHz the long init writes
# fail on some sensors with this wiring.
class Tof:
    MODEL = "VL53L1X"  # VERIFY — notes also say 3x VL53L0X
    COUNT = 4          # must match core.config.TOF_COUNT
    # Shared bus, same default address — enable each via XSHUT and reassign.
    # XSHUT GPIOs verified electrically on 2026-07-03 (matches Cirkit
    # schematic after the 4th wire moved from GPIO4 to GPIO22).
    # Labels relabelled 2026-07-14 after sensors were physically repositioned
    # (was front=26 left=25 rear=22; each faced the wrong way). Re-verify with a
    # hand-wave test. Right was unchanged ("right is always right").
    XSHUT_PINS = {"front": 22, "left": 26, "right": 16, "rear": 25}
    I2C_ADDRESSES = {"front": 0x30, "left": 0x31, "right": 0x32, "rear": 0x33}
    DISTANCE_MODE = 2        # 1=short (<=1.36m), 2=long (<=3.6m) — WRO walls need long
    TIMING_BUDGET_MS = 50    # per-sensor; 4 sensors ~ 20Hz effective loop rate


# Start button — momentary, 10k pulldown to GND (pressed = HIGH).
class Button:
    # Wired GPIO27 (header pin 13) -> button -> GND, internal pull-up.
    # Verified 2026-07-17 with robot.bench.button_test. Pressed = LOW.
    PIN = 27
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

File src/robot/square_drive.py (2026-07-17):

"""IMU square-drive test — full-capability check of the LSM6DSOX on the mat.

Drives 4 sides of a ~1m square: drive a side straight (gyro heading-hold),
turn 90 deg on the gyro, repeat. If the turns are true 90s and the sides equal,
the robot returns to where it started — the classic dead-reckoning closure test.
Everything is logged (robot.run_logger) so you can see it after: heading, raw
accelerometer, both distance estimates, and the estimated x/y path.

Two distance sources, ALWAYS both logged:
  time  : commanded_speed * MAX_SPEED integrated over dt (predictable, safe).
  accel : forward-axis accelerometer double-integrated (the "test the IMU
          accelerometer" part) — expected to be rough (gravity tilt + low-speed
          noise); the log shows exactly how rough vs the known 1m sides.

--drive-by picks which one STOPS each side (default: time, so the first run is
safe and the square is geometrically valid). In accel mode a TIME cap
(SQUARE_DIST_CAP_MM) still hard-stops the side so a bad accel estimate can't
drive the robot into a wall — give it >1.5m of clear space per side anyway.

Hot-swaps onto the same start button as open_challenge (robot.start_button):

    python3 -m robot.square_drive                 # button start, drive-by time
    python3 -m robot.square_drive --now           # skip button, 3-2-1
    python3 -m robot.square_drive --drive-by accel --now
    python3 -m robot.square_drive --dry           # calibrate + log 3s still, no motion
    python3 -m robot.square_drive --turns left    # left turns (CCW square)

Stop artemis-web first (it owns the sensors): sudo systemctl stop artemis-web
"""

import argparse
import math
import time

from core.config import (
    MAX_SPEED, SQUARE_DIST_CAP_MM, SQUARE_DRIVE_SPEED, SQUARE_KP_HOLD,
    SQUARE_SIDE_MM, SQUARE_SIDE_TIMEOUT_S, SQUARE_TURN_SPEED, TURN_STEER,
)
from robot.hal import RealHardware
from robot.start_button import arm_start
from robot.run_logger import RunLogger

G = 9.80665  # m/s^2 per g


def _angle_diff(target: float, current: float) -> float:
    """Signed smallest target-current in degrees, in (-180, 180]."""
    d = (target - current + 180) % 360 - 180
    return d + 360 if d <= -180 else d


class AccelOdometer:
    """Forward-axis accelerometer -> velocity -> distance, best-effort.

    6-axis only, so there is no true gravity compensation during motion; we
    subtract the per-axis REST bias (which includes the static gravity
    projection) and integrate the forward axis. Velocity is zeroed at each stop
    (ZUPT) so error doesn't compound across sides. Forward axis is auto-detected
    from the acceleration burst at the start of side 1 unless given.
    """

    def __init__(self, imu, fwd_axis=None):
        self._imu = imu
        self.bias = (0.0, 0.0, 0.0)     # g, per axis at rest
        self.fwd_axis = fwd_axis        # (index, sign) or None until detected
        self.vel = 0.0                  # m/s along forward
        self.dist_mm = 0.0

    def calibrate(self, seconds=1.0):
        n, sx, sy, sz = 0, 0.0, 0.0, 0.0
        t0 = time.monotonic()
        while time.monotonic() - t0 < seconds:
            ax, ay, az = self._imu.accel()
            sx += ax; sy += ay; sz += az; n += 1
            time.sleep(0.005)
        self.bias = (sx / n, sy / n, sz / n)
        return self.bias

    def _dynamic(self):
        ax, ay, az = self._imu.accel()
        return (ax - self.bias[0], ay - self.bias[1], az - self.bias[2])

    def detect_forward(self, samples):
        """samples: list of (dyn_x,dyn_y,dyn_z) taken during a forward burst.
        Forward axis = the one with the largest |mean|; sign from that mean."""
        if not samples:
            self.fwd_axis = (0, 1.0)
            return self.fwd_axis
        means = [sum(s[i] for s in samples) / len(samples) for i in range(3)]
        i = max(range(3), key=lambda k: abs(means[k]))
        self.fwd_axis = (i, 1.0 if means[i] >= 0 else -1.0)
        return self.fwd_axis

    def zupt(self):
        self.vel = 0.0

    def update(self, dt):
        """Integrate one tick; returns (dist_mm, a_fwd_ms2, dyn_tuple)."""
        dyn = self._dynamic()
        if self.fwd_axis is None:
            return self.dist_mm, 0.0, dyn
        idx, sign = self.fwd_axis
        a = dyn[idx] * sign * G
        self.vel += a * dt
        self.dist_mm += self.vel * 1000.0 * dt
        return self.dist_mm, a, dyn


def _steer_hold(hw, heading, target):
    """Heading-hold steering: positive steer raises heading (verified sign)."""
    err = _angle_diff(target, heading)
    hw.set_steering(max(-TURN_STEER, min(TURN_STEER, SQUARE_KP_HOLD * err)))


def run(drive_by="time", turns="right", wait_button=True, log=True, dry=False):
    hw = RealHardware(use_camera=False, use_imu=True, use_color=False)
    imu = hw.imu
    odo = AccelOdometer(imu)
    turn_sign = 1 if turns == "right" else -1   # right turn raises heading

    if not arm_start(wait_button):
        hw.close()
        return
    print("GO")

    logger = RunLogger("square", drive_by,
                       {"side_mm": SQUARE_SIDE_MM, "turns": turns,
                        "drive_by": drive_by}) if log else None
    print("calibrating accel bias (hold still)...")
    imu.reset_heading(0.0)
    odo.calibrate(1.0)
    print(f"  bias(g)={tuple(round(b, 4) for b in odo.bias)}")

    # estimated path (mm), starting at origin heading 0
    x = y = 0.0
    sq = _SquareLog(logger)  # writes square.csv next to the standard streams

    if dry:
        _dry_still(hw, imu, odo, sq, logger)
        hw.stop(); hw.close()
        if logger:
            logger.close({"mode": "dry"})
        return
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

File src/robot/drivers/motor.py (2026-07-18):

"""Drive motor: 12V encoder gearmotor via a TB6612FNG H-bridge (B channel).

Turns a speed fraction (-1..1) into PWM + direction, and reads the encoder for
distance travelled (which the controller uses).

Uses pigpio (daemon enabled at boot) — same stack as the servo driver, and its
callback machinery gives clean encoder edge counting.
"""

from robot.hardware_config import Motor as MotorPins

try:
    import pigpio  # type: ignore
    _PIGPIO_AVAILABLE = True
except ImportError:
    pigpio = None
    _PIGPIO_AVAILABLE = False

_PWM_RANGE = 255


class MotorDriver:
    """Drive motor with encoder odometry."""

    def __init__(self, config=MotorPins):
        self.config = config
        self._distance_mm = 0.0
        self._edges = 0
        self._direction = 1
        self._pi = None
        self._encoder_cb = None
        if not _PIGPIO_AVAILABLE:
            return
        self._pi = pigpio.pi()
        if not self._pi.connected:
            raise RuntimeError("pigpiod is not running (sudo systemctl start pigpiod)")
        for pin in (config.PIN_IN1, config.PIN_IN2, config.PIN_STBY):
            self._pi.set_mode(pin, pigpio.OUTPUT)
            self._pi.write(pin, 0)
        self._pi.set_PWM_frequency(config.PIN_PWM, config.PWM_FREQUENCY_HZ)
        self._pi.set_PWM_range(config.PIN_PWM, _PWM_RANGE)
        self._pi.set_PWM_dutycycle(config.PIN_PWM, 0)
        self._pi.write(config.PIN_STBY, 1)
        if config.PIN_ENC_B is not None:
            self._pi.set_mode(config.PIN_ENC_B, pigpio.INPUT)
            self._encoder_cb = self._pi.callback(
                config.PIN_ENC_B, pigpio.RISING_EDGE, self._on_edge
            )

    def _on_edge(self, gpio, level, tick):
        # Single encoder channel: no direction sense, so trust the commanded one.
        self._edges += self._direction

    def set_speed_fraction(self, fraction: float) -> None:
        """Drive at `fraction` of full speed; negative reverses.

        Deadband compensation: the gen-2 gearmotor + heavier chassis won't move
        below ~MOTOR_MIN_DUTY of PWM, so a raw 0.35 command (35% duty) only
        crawls. We remap |fraction| in (0,1] onto [MOTOR_MIN_DUTY, MAX_PWM_DUTY]
        so the smallest commanded speed still turns the wheels, and the fraction
        again spans the motor's *usable* range. Exactly zero = coast (duty 0)."""
        if self._pi is None:
            raise NotImplementedError("pigpio unavailable — running off-Pi?")
        c = self.config
        fraction = max(-1.0, min(1.0, fraction))
        if abs(fraction) < 1e-3:
            self._pi.set_PWM_dutycycle(c.PIN_PWM, 0)   # coast, keep last direction
            return
        lo = getattr(c, "MOTOR_MIN_DUTY", 0.0)
        duty = lo + abs(fraction) * (c.MAX_PWM_DUTY - lo)
        if fraction >= 0:
            self._direction = 1
            self._pi.write(c.PIN_IN1, 1)
            self._pi.write(c.PIN_IN2, 0)
        else:
            self._direction = -1
            self._pi.write(c.PIN_IN1, 0)
            self._pi.write(c.PIN_IN2, 1)
        self._pi.set_PWM_dutycycle(c.PIN_PWM, round(duty * _PWM_RANGE))

    def stop(self) -> None:
        """Cut drive power (coast; both inputs low)."""
        if self._pi is None:
            raise NotImplementedError("pigpio unavailable — running off-Pi?")
        c = self.config
        self._pi.set_PWM_dutycycle(c.PIN_PWM, 0)
        self._pi.write(c.PIN_IN1, 0)
        self._pi.write(c.PIN_IN2, 0)

    @property
    def distance_traveled(self) -> float:
        """Forward distance in mm from the encoder.

        Needs ENCODER_COUNTS_PER_REV + wheel circumference calibration; until
        then this returns 0 and the raw signed edge count is in `encoder_edges`.
        """
        if self.config.ENCODER_COUNTS_PER_REV:
            raise NotImplementedError("wire in counts->mm once calibrated")
        return self._distance_mm

    @property
    def encoder_edges(self) -> int:
        """Raw signed encoder edge count (direction from last command)."""
        return self._edges

    def close(self) -> None:
        if self._pi is not None:
            if self._encoder_cb is not None:
                self._encoder_cb.cancel()
            self.stop()
            self._pi.write(self.config.PIN_STBY, 0)
            self._pi.stop()

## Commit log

2026-06-16 refactor: share control core between sim and robot, add robot scaffold
    Split the control code into a shared core imported by both the simulation and
    the physical robot, and stand up the robot/ package.
    - Extract src/core/ (config, controller, sensors) as the single source of truth
    for the control brain; the sim now imports from it. SensorReading is lifted out
    of the sim's robot.py into core/sensors.py as the shared perception contract.
    - Scaffold src/robot/: a Hardware abstraction layer (hal.py), per-device driver
    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
2026-06-24 calibrate: set max steering angle to measured 35° servo throw
    The 77.48° figure came from the CAD linkage; the reassembled servo's
    actual measured throw is 35°.
2026-06-24 feat(control): gyro heading-hold driver with sign threading
    Hold a goal heading via PID on the IMU; a corner is target_heading += 90deg.
    ToF trims lateral position only when aligned. Traffic signs are threaded by a
    bounded heading offset off the lane heading (red keep right, green keep left).
    Replaces ToF wall-following and arc-geometry corners.
    Obstacle 3-lap completion ~0 -> 99%; open challenge 48/48.
2026-06-30 feat(control): dead-reckoned parallel parking with fallbacks
    Replace the omniscient-position parking with a portable maneuver on gyro heading
    + encoder + the bay's camera offset: crab into the bay, straighten to the lane,
    seat. Clean in-section stop fallbacks when the bay is unreachable / overrun /
    times out. Sim: ~70% park (full+partly), 100% clean finishes (was stuck ~78%).
2026-06-30 feat(robot): MPU6050 driver with bias calibration + ZUPT
    Calibrated gyro-Z heading: startup stationary zero-rate calibration, ZUPT (freeze
    + refine bias when still), clean config (±250°/s, 42 Hz DLPF, 200 Hz). Bounds the
    6-axis yaw drift at the source. Bench-test on the Pi; DMP is the documented upgrade.
    [hardware_config.py, imu.py]
2026-06-30 feat(web): teleop control panel with camera stream + sensor readout
    Pi serves a web app (stdlib http.server, zero deps): MJPEG camera on top,
    steering/throttle pads, speed slider, E-STOP, and a live ToF/IMU readout.
    Deadman watchdog; degrades to SIMULATED off-Pi. systemd unit for boot startup.
2026-07-05 feat(robot): pigpio-based motor/servo drivers, ToF bring-up fixes, resilient telemetry
    Switch motor and servo drivers to pigpio for jitter-free PWM and encoder
    edge counting; servo gets slew-rate-limited steering. Fix VL53L1X bring-up
    (manual init to dodge a library crash on fresh sensors, XSHUT sequencing,
    retry-with-power-cycle) and correct pin assignments per the verified
    schematic. Telemetry now degrades gracefully when ToF or IMU sensors are
    missing instead of crashing the panel.
    [camera_feed.py, hardware_config.py, motor.py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]
2026-07-13 feat(robot): flip camera 180° for upside-down mount
    [camera.py, camera_feed.py, hardware_config.py]
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2026-07-14 fix(robot): channel-A motor pins + ToF position relabel
    Motor: moved to TB6612 channel A (channel B dead at chip level).
    - PIN_IN1 -> GPIO12 (GPIO5 had a dead breadboard jumper)
    - STBY hardwired to 3.3V (dead GPIO23 jumper); GPIO23 write is now a no-op
    ToF: relabelled positions to match physical mounting after sensors were
    repositioned (front=22, left=26, rear=25; right unchanged). Re-verify with a
    hand-wave test.
    Bench tools added: chA_motor_test (Uno TB6612 spin test), imu_test (Uno MPU6050
    reader), tof_live (self-healing live ToF monitor); color_test made hot-detect.
    [chA_motor_test.ino, color_test.ino, hardware_config.py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]
2026-07-14 fix(robot): reject counterfeit/dead IMU in driver init
    The original 'MPU-6050' was a fake (relabelled ICM-20689): it ACKs I2C at 0x68,
    reports WHO_AM_I=0x98, ignores all config writes and outputs zeros, so heading()
    silently returned a constant 0 that looked healthy.
    _init_device now verifies WHO_AM_I==0x68 and that the SLEEP bit actually clears
    after a reset+wake, raising otherwise. Telemetry then reports heading=null (an
    honest fault) instead of a misleading 0. Genuine MPU6050 (0x68) now installed.
    [imu.py]
2026-07-14 feat(robot): color sensor on dedicated i2c-3 bus + smbus2 driver
    TCS34727 (ID 0x4d) shares 0x29 with the VL53L1X default, which broke ToF
    bring-up on the main bus. Move it to its own software I2C bus (i2c-gpio overlay,
    SDA=GPIO20 SCL=GPIO21, /dev/i2c-3) via hardware_config.Color.BUS_ID.
    Implement color.py against smbus2: verify the chip ID, set integration/gain,
    expose raw() + normalized() reads, and nearest-centroid detect() that requires
    calibrated THRESHOLDS (raises until calibrated rather than guessing).
    [color.py, hardware_config.py]
2026-07-15 feat(robot): ToF-only open challenge with noise-hardened sensing
    IMU and colour sensor are gone from the build; the open challenge now runs
    a four-ToF wall-follower (core/wall_follow_controller.py + robot/open_challenge.py,
    RealHardware gains use_imu/use_color flags).
    Bench ToF dropouts (233,233,4000,234) sim-proven to wreck runs: front spikes
    false-trigger corners (12 turns -> 21, premature finish, 0/10 valid). Fixes:
    - corner trigger debounce (CORNER_PERSIST_TICKS=3) + trigger 400->450mm to
    compensate; default/wide tracks now 9-10/10 valid under 5% dropout noise
    - outlier gate in shared core/tof_filter.py (driver + sim run identical code):
    reject >150mm jumps unless confirmed by the p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
    [hal.py, open_challenge.py, tof.py]
2026-07-15 feat(core): gyro-free heading fusion for the wall-follower
    Two heading sources replace the dead IMU:
    - core/tof_heading.py: heading from least-squares slope of side-ToF distances
    over ~0.33s windows (sin(theta) = d_side_dot / v); reset around turns
    - core/vision_heading.py: absolute heading from the camera wall-base slope,
    pure numpy; wall = dark AND chroma-neutral pixels (rejects the navy lane
    line), base found bottom-up (background clutter can't be selected) —
    validated on frames from the 2026-07-14 run recordings
    Controller steers on KP_WALL*offset - KP_HEADING_WF*heading, fusing 0.7 ToF /
    0.3 vision when both are live (SensorReading.vision_heading, None in sim).
    Renamed the wa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
2026-07-15 fix(web): stable camera stream + teleop robustness; ignore external/
    - camera_feed: single shared capture thread with a latest-frame slot —
    concurrent capture_array() on one Picamera2 deadlocks when a second
    client connects or a browser reconnects
    - request BGR888 (picamera2 format names are reversed: it delivers RGB)
    to fix the red/blue swap in the stream
    - ARTEMIS_NO_CAMERA=1 env escape hatch: a wedged libcamera init blocks in
    uninterruptible I/O before the web port binds, try/except can't catch it
    - app: flush each MJPEG frame instead of letting the socket buffer
    - index.html: teleop send loop cleanup
    - gitignore external/ (reference clones of other teams' repos)
    [app.py, camera_feed.py]
2026-07-15 docs(video): teleop dashboard run recordings, 2026-07-14
    Two runs driven from the web dashboard on the practice floor: live fisheye
    feed + four ToF readouts (front/left/right/rear), no IMU heading. Shows the
    wide-angle camera resolving the blue/orange lane lines in low light — the
    basis for camera-side corner detection and wall-base heading estimation.
    Compressed to ~2MB each from the 48/93MB screen-recording originals
    (half-scale, crf 26); originals kept local via gitignore.
2026-07-15 fix(core): wide-corridor turns + WRO ground-truth scoring for the open sim
    New test_open_score.py scores runs per WRO rules from sim ground truth
    (swept angle -> sections/laps + finish-in-start-section bonus, max 30).
    It exposed that the earlier 'valid' criterion (turns/time/collisions)
    missed the robot ping-ponging in wide corridors without orbiting:
    - turn exit per-side check (< SIDE_WALL_VALID) is unsatisfiable for a
    centred robot in a 1000mm corridor -> spins of 150-330 deg; replaced
    with a width-agnostic left+right sum test (SIDE_SUM_REALIGNED)
    - turn progress is now dead-reckoned kinematically (arc = v*tan(steer)/
    wheelbase, no gyro/encoder), exit window [TURN_ARC_MIN, TURN_ARC_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
2026-07-15 fix(core): perfect open-challenge score — phantom triggers, arc cap, silent corners
    Score-harness-driven fixes, each diagnosed from ground-truth traces:
    - corner trigger now also requires seeing the corner mouth (one side
    reading clear across the track, > CORNER_OPEN_SIDE): instrumented real
    triggers read >= 2400mm on the open side, phantoms (front ToF catching
    a side wall diagonally after a heading excursion) <= 1360mm. Phantoms
    were double-counting corners and causing the noisy-run collisions
    - TURN_ARC_MAX 115 -> 95: dead-reckoned arc overestimates true rotation
    (servo slew), so 115 forced ~25 deg exit overshoots whose recovery lost
    the race to the inner wall in 600mm corri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
2026-07-16 feat(robot): three run modes for mat testing — tof / fusion / imu
    python -m robot.open_challenge [--mode tof|fusion|imu] [--now] [--width 600]
    - tof (default): the proven ToF-only wall-follower, unchanged
    - fusion: + robot/camera_worker.py, a 10Hz Picamera2 thread feeding
    vision_heading (wall-base slope) and the corner line colour into the
    same controller; direction now locks by rule from the first line seen
    (orange = CW) with the geometric guess as no-camera fallback —
    sign convention verified by the sim's own mat lines (still 80/80)
    - imu: the gyro Controller as a contingency for a trustworthy 9-axis
    IMU; camera lines replace the colour sensor for corner triggering and
    a d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
    [camera_worker.py, open_challenge.py]
2026-07-16 feat(robot): LSM6DSOX IMU driver, auto-detected, bench-verified on the Pi
    New Lsm6dsoxDriver (0x6A, WHO_AM_I 0x6C verified genuine on-robot
    2026-07-16) sharing the heading logic with the MPU6050 driver via a
    _HeadingIntegrator base: startup bias calibration, ZUPT freeze+refine,
    gyro-Z integration at ±250dps. make_imu() probes the bus and prefers
    the LSM6DSOX; RealHardware now uses the factory.
    Live bench results (Pi 3B+, robot stationary):
    - calibrated bias -0.23 dps, stable across runs
    - 30s with ZUPT: 0.000 deg drift
    - 30s RAW integration (no ZUPT): +0.033 deg => ~0.07 deg/min,
    ~7x better than the calibrated MPU6050 target (0.5 deg/min)
    Still to verify once mounted: GYRO_Z_SIGN (spin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
    [hal.py, hardware_config.py, imu.py]
2026-07-16 feat(robot): IMU-referenced 90-degree turn test + live heading on dashboard
    - robot/turn90.py: real-hardware corner turn (full lock, corner speed)
    closed on the IMU heading, with front-ToF abort and a built-in
    GYRO_Z_SIGN check. On-robot: right turn swept 90.9 deg in 2.4s and
    exposed the flipped Z axis; ImuLsm.GYRO_Z_SIGN = -1 (verified with a
    left turn: -90.3 deg, correct sign)
    - web/telemetry.py: make_imu() (LSM6DSOX picked up automatically) and a
    50Hz background integration thread, so heading accuracy no longer
    depends on the dashboard poll rate; HEADING panel now live
    - diagnosis note: 'right ToF dead / camera dead' on the dashboard was
    an ownership conflict, not wiring —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
    [hardware_config.py, telemetry.py, turn90.py]
2026-07-16 fix(robot): mat-run hardening — web-app ownership guard, camera release
    - open_challenge refuses to start while artemis-web answers on :8000
    (it owns the camera and the ToFs; a second TofArray resets the
    sensors under it and two owners corrupt reads mid-run)
    - CameraWorker.close() now releases the Picamera2 device (stop() alone
    keeps it acquired and the next owner gets 'Device or resource busy')
    On-robot smoke (both competition stacks, no motion):
    - fusion (camera+ToF): camera live, line detection firing, wall-base
    vision heading ~0 on a level view, all four ToFs ranging
    - imu (IMU+camera+ToF): LSM6DSOX heading integrating, same camera and
    ToF health
    Sim re-verified at HEAD: gyr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
    [camera_worker.py, open_challenge.py]
2026-07-17 fix(robot): start button on RPi.GPIO (GPIO27), not pigpio — stops ToF wipeout
    The pigpio start-button path required the pigpiod daemon, and STARTING
    that daemon resets the GPIO subsystem, dropping the ToF XSHUT lines LOW —
    which powers down all four VL53L1X and drops them off the I2C bus (they
    lose their reassigned 0x30-0x33 addresses and revert to 0x29). This is
    what killed the dashboard's ToF readings after a button_test run.
    Fix: button now uses RPi.GPIO — the SAME library the ToF driver uses for
    XSHUT — so there is no daemon and no pin-state reset. Verified on-robot:
    GPIO27 reads idle=1, ToFs stay alive (0x30-0x33 all ACK) during a button
    read, and 'open_challenge --mode imu' re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
    [button_test.py, hardware_config.py, open_challenge.py]
2026-07-17 feat(robot): run flight-recorder — sensor + camera detection logs
    RunLogger (robot/run_logger.py) writes a timestamped run dir under
    ~/artemis/logs/ with three time-correlated streams (t = seconds since GO):
    - sensors.csv: per control tick (~30Hz) — 4 ToF, IMU heading, commanded
    steering/speed, controller state + turns, and the camera line/heading
    the controller saw that tick
    - camera.jsonl: per perception frame (~10Hz) from CameraWorker — line
    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
2026-07-17 feat(robot): IMU square-drive test + shared start-button module
    robot/square_drive.py: drive 4 sides of a ~1m square (gyro heading-hold
    straights, gyro-referenced 90 turns), returning to start — the dead-
    reckoning closure test, fully logged.
    - distance: TWO sources always logged — time (commanded speed*MAX_SPEED,
    the safe default that STOPS each side) and accel (forward-axis
    accelerometer double-integrated, the 'test the IMU' part). --drive-by
    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
2026-07-17 feat(robot): ASCII path plot in log_timeline + standalone boot-run service
    - log_timeline: square runs now render an ASCII x/y path plot (S=start,
    E=end, numbered corners, closure-gap readout) — works over SSH, no GUI
    or matplotlib. Answers 'did the square close' at a glance.
    - artemis-run.service: standalone button-armed run. Boot the Pi, it loads
    the script and waits for the physical button — no laptop, no network.
    Runs one attempt then exits (Restart=no, never re-drives). Conflicts with
    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
2026-07-17 docs: publish CAD models (v1 + current), wiring schematic, vehicle photos
    - Reorganize models/: v1/ = original small chassis (retired — too cramped to
    disassemble for wiring debugging), print/ + cad-source/ = current design
    - Add 6 vehicle photos, sim screenshots, wiring SVG
    - Narrow .gitignore from blanket binary/doc excludes to targeted local-only paths
    [ARM_LINKAGE.STL, AXLE.STL, AXLE_2.STL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]
2026-07-17 docs: rewrite README around the five Appendix C criteria (5000+ chars)
    Structured to mirror the engineering-journal rubric: mobility, power/sensors,
    software architecture (state machine diagram), engineering decisions with
    evidence, reproduction steps, and the sim->bench->field testing workflow.
2026-07-17 docs: accurate models README (gen-2 chassis + body iteration history), fix vehicle specs
    Root README vehicle table now describes the physical gen-2 chassis (208mm,
    55mm wheels) instead of the v1 constants still modeled in core/config.py,
    with the sim-recalibration caveat stated explicitly. models/README rewritten:
    current tub+lid body design, print notes, 10-revision iteration lessons, and
    the v1 design preserved as a documented retired generation.
2026-07-17 docs: power & sensor architecture writeup, tests.md, requirements files
    - docs/power-and-sensors.md: power budget (datasheet-typical, labeled as such),
    bus architecture lessons, sensor placement rationale, per-device calibration
    procedures, failure-mode table
    - tests.md: sim -> bench -> field workflow with per-suite pass bars
    - requirements.txt (dev/sim) + requirements-robot.txt (Pi runtime)
    - README links updated
2026-07-17 docs: schemes README — explain the wiring diagram, date it, list known deltas
2026-07-17 feat(config): gen-2 chassis geometry + controller retune, sim-revalidated
    config.py now models the gen-2 vehicle (208x148mm, wheelbase 152mm, track
    120mm, 55mm wheels, 300RPM rated gearmotor -> MAX_SPEED ~864mm/s) instead
    of the retired v1 (140mm, 30.4mm LEGO wheels, ~216mm/s).
    Retuned for the new geometry (sim sweeps, 10 seeds):
    - wall follower: SPEED_OPEN_CRUISE 0.95->0.35 (~302mm/s), SPEED_OPEN_CORNER
    0.70->0.22, CORNER_TRIGGER_FRONT 450->600 (217mm full-lock radius needs an
    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
2026-07-17 docs: BOM/cost tables, 2S LiPo battery swap, remove stale encoder-in-use claims
    - docs/bom.md: current-build cost table (from the team BOM sheet) plus a
    retired-parts table with the reason each part was replaced
    - Battery: 3x18650 holder -> 7.4V 2S 5000mAh protected LiPo everywhere
    (README, power doc, models README, schemes deltas)
    - Encoder: documented as unused; control stack is encoder-free (README,
    models, schemes, robot README, control-architecture note)
    - src/robot/README: stale 'scaffold, does not run' status corrected
2026-07-17 docs: add 2S LiPo label photo, link from power doc and BOM
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2026-07-18 cad: full gen-2 assembly (STEP + Fusion source), render-ready merge with lid; motor is JGA25-370
    The assembly STEP names the real components (JGA25-370 gearmotor, SG90,
    Improved frame) — corrected the docs that guessed N20-class.
    full_assembly_with_lid.step places body_lid at the tub's assembly offset
    (+1.2, +8.4, +0.3 mm), verified by render.
    [New assembly test on new.f3d, New assembly test on new.step]
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2026-07-18 docs: tighten wording in models and power docs
2026-07-18 fix(robot): slow speed, wall-follower stuck-guard, imu 90-degree hard cap
    Three mat-run fixes after the fusion run drove into a wall and spun its
    turn counter to 61:
    - motor: cap top speed via MAX_PWM_DUTY 1.0->0.62 (with MOTOR_MIN_DUTY 0.45
    ->0.42) so the real robot is slower and can complete corners, without
    touching the shared SPEED_OPEN_* fractions the sim needs to finish 3 laps
    - WallFollowController: collision guard — a front ToF pinned < STUCK_FRONT_MM
    for STUCK_TICKS is a jam, not a corner; reverse out and retry up to
    MAX_STUCK_RECOVERIES, else stop. Kills the grind-and-count-phantom-turns
    loop (front was pinned ~5mm for 20s, turns ran to 61)
    - gyro Controller: hard-cap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
    [hardware_config.py, motor.py]
2026-07-18 feat(core): ImuFusionController — IMU-executed turns, ToF-detected corners
    The real-robot open-challenge driver that fixes both mat failures (colour-
    triggered corners fired early; ToF full-lock turns hugged the inside wall):
    - straights: IMU heading-hold onto a cardinal + gentle ToF centring trim
    - corner DETECT: front ToF wall closing + a side open (the mouth), debounced —
    geometry, not colour, so early/repeat line sightings can't false-trigger
    - corner EXECUTE: bump heading target ±90 and PID onto it — the turn ends
    exactly 90 later, aligned and re-centred, no full-lock inside-wall hug
    - direction: camera line colour locks turn sense (orange=CW/right,
    blue=CCW/left); wall-dis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
    [open_challenge.py]
2026-07-18 tune(robot): raise motor duty so cruise doesn't stall
    imufusion run held heading 90s but the motor stalled on the straight (cruise
    was ~49% duty, at the static-friction edge). MAX_PWM_DUTY 0.62->0.78 and
    MOTOR_MIN_DUTY 0.42->0.48 lift cruise/corner clear of the break while keeping
    corners controllable. Controller was flawless — this is a power tune only.
    [hardware_config.py]
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2026-07-18 fix(robot): faster + more permissive colour-line detection
    Colour mode ran past lines unless crawling. Two fixes:
    - speed: integration 50ms->10ms (less motion blur) + gain 4x->16x (light
    budget), and a ColorWorker background thread reads at ~80Hz and latches a
    line for 150ms so a crossing that flashes between 30Hz control ticks isn't
    missed. run_color_imu uses the worker (single sensor owner).
    - classify: nearest-centroid let the white 'none' centroid steal blurred line
    reads. Replaced with a permissive r-b threshold ((R-B)/clear): orange if
    >0.18, blue if <0.05, else none — widens line acceptance off the white value
    (0.11) while still excluding white. MIN_CLEAR guards near-dar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
    [color.py, color_worker.py, hardware_config.py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]
2026-07-18 fix(core): colour DIRECTS, front-wall ToF FIRES the turn (timing fix)
    Colour mode caught the wrong line: on a CW mat the orange ENTRY line is
    crossed before the corner (front wall still ~2800mm), so requiring a ToF
    corner-confirm at the colour instant rejected orange, and a later blue read
    fired instead. Redesign:
    - _note_color latches the entry colour seen anywhere on the straight (once
    direction locks, only the entry colour is remembered; exit colour ignored)
    - the front-wall ToF (closing + a side open, debounced) FIRES the 90deg turn;
    the latched colour only sets direction (orange=right, blue=left), geometry
    as fallback
    So colour directs, ToF confirms the corner is here, IMU execute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
    [hardware_config.py]
